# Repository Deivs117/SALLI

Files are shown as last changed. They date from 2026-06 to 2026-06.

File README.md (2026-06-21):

# SALLI: Salamander Autonomous Locomotion on Land Infrastructure

SALLI is an open-source, low-cost, and modular mechatronic platform designed to study bio-inspired terrestrial locomotion. Drawing inspiration from the sprawling gait of the salamander, this project integrates custom 3D-printed mechanical linkages, dedicated modular printed circuit boards (PCBs), lightweight embedded ESP-IDF firmware, and high-level Python control algorithms.

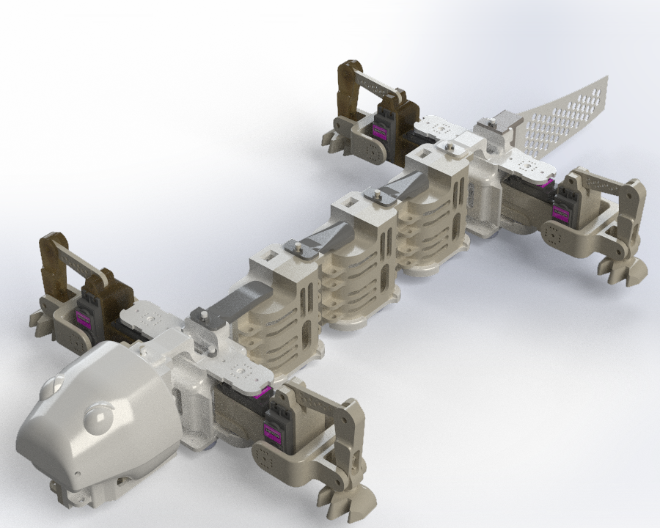
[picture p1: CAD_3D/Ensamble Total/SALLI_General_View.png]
SALLI General View


---

## Project Vision & Philosophy

Traditional robotics platforms often suffer from high manufacturing costs, complex monolithic assemblies, and poor reparability. SALLI was conceived under a different paradigm:
* **True Modularity:** Every physical segment—whether a spinal oscillator, a locomotor leg, or a sensory head—uses a standardized mechanical and electrical connection interface. Segments can be chain-linked dynamically to increase or decrease the robot's degrees of freedom (DoF).
* **Low Cost & Accessibility:** Designed to be accessible to students, researchers, and hobbyists. The structural parts are optimized for standard FDM 3D printing, and the electronics rely on budget-friendly, high-performance ESP32-C3 microcontrollers and standard micro servos.
* **Easy Maintenance & Repair:** Field repairs can be executed swiftly. Damage to a single segment does not compromise the whole robot; the offending module can be disconnected and swapped out in minutes.

---

## System Architecture

The project is structurally divided into four cohesive domains:

```mermaid
graph TD
    A[Control Codes - Python PC] <-->|UDP over Wi-Fi| B[Firmware - ESP-IDF Master AP]
    B <-->|UDP Multicast / Serial Bus| C[Firmware - ESP-IDF Slave Node]
    B -->|PWM Signals| D[Custom PCBs / Power Rails]
    C -->|PWM Signals| D
    D -->|Actuation| E[CAD 3D - Physical Modules]

```

1. **`CAD_3D/` (Mechanical Architecture):** Multi-segment structure utilizing bio-mimetic joint limits and sprawling kinematics.
2. **`PCBs/` (Electrical Architecture):** Modular bus system delivering isolated power lines (to prevent servo-induced voltage brownouts) and standardized signal traces.
3. **`Firmware/` (Embedded Systems):** High-efficiency ESP-IDF C-code implementing an Access Point control loop and UDP-based communication over ESP32-C3 chips.
4. **`ControlCodes/` (High-Level Control & Autonomy):** Python orchestrator supporting manual teleoperation, automatic parameter identification, and servo calibration.

---

## Repository Directory Tree

```text
SALLI/
├── .gitignore                   # Global file and directory exclusions
├── README.md                    # Root-level project documentation (This file)
│
├── CAD_3D/                      # Mechanical assemblies and components
│   ├── Cabeza V3/               # Sensory head module
│   ├── Cola/                    # Stabilizing tail segment
│   ├── Ensamble Total/          # Master digital design assembly
│   ├── Módulo de Patas V3/      # Sprawling leg kinematics module
│   ├── Oscilatorio V4/          # Daisy-chainable spinal segments
│   └── Patines/                 # Passive ground contact slide-pads
│
├── ControlCodes/                # High-level Python control ecosystem
│   ├── Calibration.py           # Multi-servo offset calibration utility
│   ├── SALLI.py                 # Core autonomy and CPG state engine
│   └── Teleoperation.py         # Human-in-the-loop manual controller
│
├── Firmware/                    # Low-level ESP-IDF software
│   ├── Acces Point Sally/       # Master AP, computational control, and state processor
│   └── WIFI_Movement/           # Slave node receiver executing raw joint positions
│
└── PCBs/                        # Electrical schematic and board layouts
    ├── Camera/                  # Visual feedback capture module
    ├── HeadModule/              # Central micro-controller carrier PCB
    ├── Legs_Module/             # High-current servo driver PCB
    └── Oscilatory/              # Passive signal-passthrough spine PCB

```

---

## Biological Locomotion Model

SALLI's movement is mathematically governed by a **Central Pattern Generator (CPG)** model. This system represents networks of coupled neural oscillators that generate rhythmic patterns without sensory feedback.

The phase relation between the body segments ($i$) and limbs ($j$) is modeled using coupled differential equations:

$$\frac{d\theta_i}{dt} = 2\pi \nu_i + \sum_{j} w_{ij} \sin(\theta_j - \theta_i - \phi_{ij})$$

Where:

* $\theta_i$ represents the instantaneous phase of the $i$-th oscillator.
* $\nu_i$ is the intrinsic frequency of the segment.
* $w_{ij}$ dictates the coupling strength between neighboring segments.
* $\phi_{ij}$ is the target phase bias defining traveling waves for swimming or crawling.

This math is processed in real-time between the `ControlCodes` layer and the `Firmware` layer to ensure fluid, life-like movements.

---

## Quick Start

### 1. Requirements & Tools

* **CAD:** Autodesk Fusion 360, SolidWorks, or FreeCAD to view STEP/STL files.
* **Firmware development:** Espressif ESP-IDF SDK (v5.1 or later recommended).
* **Control Station:** Python 3.10+ with standard networking libraries.

### 2. Basic Setup

To clone the repository and initialize the project:

```bash
git clone [https://github.com/YourUsername/SALLI.git](https://github.com/YourUsername/SALLI.git)
cd SALLI

```

---

## Academic Context

This project was developed at **Universidad Autónoma de Occidente (UAO)**, Cali, Colombia, within the Faculty of Engineering. It serves as an open-source platform to advance research in bio-inspired robotics, kinetic efficiency, and distributed embedded networks.

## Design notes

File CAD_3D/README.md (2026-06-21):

# SALLI: Mechanical CAD & Bio-Inspired Designs

This directory contains the entire three-dimensional mechanical framework of SALLI. The structural engineering is tailored for high accessibility, durability, and rapid assembly, allowing students and researchers to fabricate a bio-inspired robot using standard **Fused Deposition Modeling (FDM) 3D printers**.

---

## Directory Mapping & Module Functions

To accommodate global developers, the folder names are kept in Spanish as generated by our design pipeline, but correspond to the following technical subsystems:

| Folder Name | English Designation | Core Mechanical Role |
| :--- | :--- | :--- |
| `Cabeza V3` | **Head Module V3** | Houses the primary ESP32-C3 processor, sensory electronics, power switch routing, and visual streaming camera. |
| `Oscilatorio V4` | **Oscillatory Spine V4** | Standardized vertebrae module that provides one horizontal rotary Degree of Freedom (DoF) to form the lateral undulations of the spine. |
| `Módulo de Patas V3` | **Sprawling Leg Module V3** | Houses the micro servos responsible for controlling the crawling limbs, transforming standard rotary motion into forward driving force. |
| `Cola` | **Tail Module** | A series of passive/active segments that balance center of mass shifts and provide inertial stabilization. |
| `Patines` | **Underbody Slides / Skates** | Passive support structures positioned along the belly to minimize frictional dragging forces and maintain consistent ground clearance. |
| `Ensamble Total` | **Master CAD Assembly** | Complete workspace containing tolerances, fast assembly fasteners, and inter-segment limits. |

---

## Mechanical Modularity Philosophy

The backbone of SALLI relies on a **dovetail-inspired sliding locking mechanism** secured with standard metric machine screws. 

```mermaid
flowchart LR
    %% Definición de los Módulos Físicos
    ModuleA["Module N-1: Passive Tail"]
    ModuleB["Module N: Active Actuator"]

    %% Interfaz Central de Conexión
    subgraph Interface ["Connector Interface"]
        direction TB
        Slot["Dovetail Slot Joint"]
        Bolt["M3 Retaining Bolt"]
        Slot --- Bolt
    end

    %% Relaciones de Ensamble y Dirección de Acople
    ModuleA ==>|Sliding Alignment| Slot
    ModuleB ==>|Mechanical Lock| Bolt

    %% Estilos de Ingeniería Libres de Emojis
    style ModuleA fill:#1a1a1a,stroke:#444,stroke-width:2px,color:#fff
    style ModuleB fill:#1a1a1a,stroke:#444,stroke-width:2px,color:#fff
    style Interface fill:#2d2d2d,stroke:#666,stroke-width:1px,color:#fff
    style Slot fill:#3d3d3d,stroke:#777,color:#fff
    style Bolt fill:#3d3d3d,stroke:#777,color:#fff
```

* **No Glue Required:** All connections are held in place mechanically, ensuring that cracked components can be easily unscrewed, reprinted, and replaced.
* **Symmetrical Design:** The spinal modules share symmetrical left/right geometry, minimizing the unique parts inventory required for manufacturing.
* **Adaptive Kinematics:** By modifying the number of `Oscilatorio` modules, you can alter the physical body length, shifting the gait dynamics from a compact lizard style to an elongated serpentine flow.

---

## Manufacturing & FDM Print Specifications

To achieve optimal strength-to-weight ratios without requiring industrial printers, we recommend printing the parts using the following settings:

* **Material:** **PETG** (Highly recommended for high impact strength and natural flex tolerance under heavy joint torques) or **PLA+** (for easy printing with high tensile strength).
* **Layer Height:** `0.2 mm` (Balanced speed and feature tolerance).
* **Infill Density:** * Spine/Structural parts: `30%` Gyroid or Grid infill.
* Leg linkages/Connectors: `50%` Gyroid infill (Crucial for withstanding torsional shear stress).

* **Wall Lines:** Minimum `3` perimeter loops.
* **Orientation:** Print all modules with their flat connector faces touching the build plate to eliminate the need for excessive support structures.

---

## Hardware Fasteners Bill of Materials (BOM)

To assemble the CAD files, ensure you have the following hardware:

* **Screws:** M3 socket head screws (various lengths: $8\text{ mm}$, $12\text{ mm}$, and $16\text{ mm}$).
* **Nuts:** M3 hex locknuts (nyloc recommended to prevent loosening from walking vibrations).
* **Servos:** High-torque metal-geared micro servos (e.g., MG90S or compatible standard micro-sizes).

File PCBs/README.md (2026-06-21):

# SALLI: Custom Electronic PCBs

This directory contains the electrical designs for SALLI's custom printed circuit boards. The electronic system is engineered to solve a common pitfall in amateur robotics: messy, unreliable wiring harnesses that introduce high resistance, noise, and power failures.

---

## Electrical Architecture Overview

SALLI uses a decentralized, modular electrical bus system. Power is distributed along the spine via a ruggedized internal backbone, preventing major voltage drops from affecting the master microcontroller.

```mermaid
flowchart TD
    %% Definición de Bloques Principales
    Battery["Main Battery Pack<br>(2S LiPo / 7.4V)"]
    RegServo["Servo Regulators<br>(5V - 6V)"]
    RegLogic["Logic Regulators<br>(3.3V)"]
    
    %% Representación del Bus Centralizado
    subgraph Bus ["SALLI Power & Communication Bus"]
        direction LR
        Lines["Power Rails & Signal Traces"]
    end

    %% Módulos de Destino (PCBs)
    Head["HeadModule<br>(Master Processing)"]
    Osc["Oscilatory<br>(Spine Segment)"]
    Legs["Legs_Module<br>(High-Current Driver)"]

    %% Conexiones e Interconexión Eléctrica
    Battery ==>|Raw VCC| RegServo
    Battery -->|Raw VCC| RegLogic
    
    RegServo ==>|High-Current Servo VCC| Lines
    RegLogic -->|Isolated Clean 3.3V| Lines

    Lines ==> Head
    Lines ==> Osc
    Lines ==> Legs

    %% Estilos de Ingeniería Avanzada (Sin Emojis)
    style Battery fill:#1a1a1a,stroke:#bf616a,stroke-width:2px,color:#fff
    style RegServo fill:#2d2d2d,stroke:#d08770,stroke-width:1px,color:#fff
    style RegLogic fill:#2d2d2d,stroke:#ebcb8b,stroke-width:1px,color:#fff
    style Bus fill:#232831,stroke:#81a1c1,stroke-width:2px,color:#fff
    style Lines fill:#3b4252,stroke:#88c0d0,stroke-width:1px,color:#fff
    style Head fill:#1a1a1a,stroke:#4c566a,stroke-width:1px,color:#fff
    style Osc fill:#1a1a1a,stroke:#4c566a,stroke-width:1px,color:#fff
    style Legs fill:#1a1a1a,stroke:#4c566a,stroke-width:1px,color:#fff
    
    %% Definición de grosores de línea para diferenciar potencia de lógica
    linkStyle 0 stroke:#bf616a,stroke-width:3px;
    linkStyle 1 stroke:#ebcb8b,stroke-width:1px;
    linkStyle 2 stroke:#d08770,stroke-width:3px;
    linkStyle 3 stroke:#ebcb8b,stroke-width:1px;
```

---

## Board Subsystems & Responsibilities

The electrical system is divided into four main board profiles:

### 1. `HeadModule` (Master Processing PCB)

The central board of the robot, acting as SALLI's head controller.

* **MCU Support:** Integrates the footprint for the **ESP32-C3 Mini** board.
* **Power Filtering:** Features heavy ceramic and electrolytic capacitor banks to filter out high-frequency noise induced by servo inductive kickbacks.
* **Sensor Hub:** Routes dedicated pins for IMUs (Inertial Measurement Units for tilt and balance detection) and external range sensors.

### 2. `Oscilatory` (Spine Segment PCB)

These are passive/semi-active distribution boards designed to be chain-linked together.

* **The SALLI Bus:** Passes power (VCC and GND) and communication channels downstream to consecutive modules.
* **Servo Tap:** Provides local, filtered power connectors for the local spinal deflection servo, keeping cabling lengths under $20\text{ mm}$.

### 3. `Legs_Module` (High-Current Driver Board)

Because the limbs support the entire weight of the robot and drive forward crawling forces, they demand significant active currents.

* **High-Current Traces:** Features wide copper traces capable of handling sustained currents of up to $3\text{ A}$ during crawling cycles.
* **Independent Power Regulation:** Standardizes opto-couplers or isolation resistors to prevent sudden physical motor stalls from corrupting the main microcontroller's logical operations.

### 4. `Camera` (Vision Expansion Board)

An optional expansion PCB tailored to hold camera modules (such as ESP32-CAM or specialized small SPI cameras) to enable visual-spatial telemetry.

---

## Design Guidelines

* **Trace Width Selection:** * Power paths ($VCC\_SERVO$, $GND$) are set to a minimum of `1.5 mm` width to minimize resistance and prevent thermal stress under heavy load.
* Logic lines ($TX$, $RX$, $PWM$) are kept at standard `0.254 mm` traces.

* **Decoupling Strategy:** Each module places a `100uF` electrolytic capacitor directly in parallel with the local servo power terminal, supplemented by a standard `0.1uF` ceramic capacitor close to the logic rails to handle high-frequency voltage ripples.
* **Standardized Pin Headers:** Connectors use standard, highly accessible, polarized headers (like JST-XH or XT30/XT60 for power entry) to ensure mistake-proof assembly by students.

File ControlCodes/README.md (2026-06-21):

# SALLI: Python High-Level Control Codes

This directory contains the high-level Python software suite designed to orchestrate SALLI's telemetry, user interaction, automated object-tracking loops, and physical joint calibration. These components interface directly with the ESP32-C3 master microcontroller over local network protocols to close the control loop.

---

## Software Component Architecture

The Python workstation layer processes non-real-time heavy computations (such as deep learning inference and graphic user interfaces) and communicates with SALLI's local Wi-Fi gateway.

```mermaid
graph TD
    subgraph Workstation [High-Level Workstation]
        A[Teleoperation.py] -->|Subprocess Launch| B[Calibration.py]
        C[SALLI.py] -->|YOLOv8 Engine| D[Inference Thread]
        D -->|Target Vector Calculation| E[Network Request Loop]
    end

    subgraph ESP32 [Embedded Gateway]
        F[Master ESP32-C3 AP]
        G[ESP32-CAM Board]
    end

    E -->|HTTP REST /drive| F
    B -->|HTTP POST /calib| F
    A -->|HTTP GET /frame| G

```

### 1. SALLI.py: Vision-Based Autonomous Navigator

This application establishes an autonomous closed-loop tracking system using a local webcam or HTTP camera stream. It utilizes a custom-trained **YOLO (You Only Look Once)** object detection network to identify targets and dynamically adjust the robot's locomotion vector.

* **Asynchronous Deep Learning Inference:** A dedicated background thread runs the YOLO engine (`my_model.pt`) on incoming image buffers, maintaining frame-rate stability on the main UI thread.
* **Proportional Target Tracking:** Translates spatial coordinate deviations of target bounding boxes into steering adjustments and speed curves.
* **Proximity Stop Safeguards:** Automatically switches states to idle/stop when the target bounding box area exceeds a safety threshold, preventing physical collisions.

### 2. Teleoperation.py: Interactive Driver Station

Provides a graphical user interface (GUI) developed in Tkinter with a dark palette.

* **Asynchronous Video Stream Receiver:** Connects to an external ESP32-CAM module, pulling JPEG frames continuously via HTTP GET requests and dynamically resizing the viewport buffer to maintain low latencies.
* **Remote Mode Transitioning:** Sends immediate state changes to the master robot, switching operating modes (`calib`, `preview`, `run`) via high-speed HTTP parameters.
* **Dynamic Controller Spawning:** Spawns the calibration tool as an independent sub-process, ensuring modular execution.

### 3. Calibration.py: Joint Offset Tuner

Compensates for mechanical assembly tolerances and variations across budget analog micro-servos.

* **Trimming Array Constructor:** Allows users to adjust mechanical offsets for 14 independent servo lines divided into logical anatomical groups:
* Left and Right Limbs (`p1` through `p8`)
* Anterior and Posterior Vertebrae (`o1` through `o6`)

* **NVS Serializer:** Collects active slider adjustments and structures a serialized JSON payload transmitted via HTTP POST. This configuration is written directly to the non-volatile storage (NVS) partition of the ESP32-C3 chip.

---

## Mathematical Formulations

To ensure a high level of technical rigor, the mechanical, kinematic, and vision processing layers are governed by the following mathematical frameworks.

### 1. Servo Offset Projection Model

Let $\theta_{\text{logical}, i}$ be the abstract, mathematically calculated joint angle outputted by the locomotion algorithm for servo $i$, where $\theta_{\text{logical}, i} \in [-90^\circ, 90^\circ]$.

Due to physical mounting misalignments, a pure logical angle does not map to a physically straight joint. We define $\theta_{\text{base}} = 90^\circ$ as the physical midpoint of the servo's standard $180^\circ$ range. The final commanded angle transmitted to the physical actuator $\theta_{\text{target}, i}$ is calculated as:

$$\theta_{\text{target}, i} = \theta_{\text{logical}, i} + \theta_{\text{base}} + \Delta\theta_i$$

Where:

* $\Delta\theta_i \in [-45^\circ, 45^\circ]$ represents the calibration trim offset for servo $i$, modified in `Calibration.py`.

During calibration mode, the software enforces $\theta_{\text{logical}, i} = 0^\circ$. Thus, the physical output reduces to:

$$\theta_{\text{target}, i} = 90^\circ + \Delta\theta_i$$

By adjusting $\Delta\theta_i$ until the joint is perfectly perpendicular, the system captures mechanical error offsets and saves them to the ESP32-C3 NVS.

### 2. YOLO-Based Closed-Loop Proportional Steering Logic

When running in autonomous tracking mode (`SALLI.py`), the tracking error $e(t)$ is computed from the bounding box's horizontal centroid $x_{\text{bbox}}$ relative to the total horizontal frame resolution $W$:

$$e(t) = \frac{x_{\text{bbox}} - \frac{W}{2}}{\frac{W}{2}} = \frac{2 \cdot x_{\text{bbox}}}{W} - 1$$

Where:

* $e(t) \in [-1.0, 1.0]$. A negative value indicates the target is to the left, and a positive value indicates the target is to the right.

To prevent joint wear from continuous micro-oscillations, we implement a symmetrical deadzone $\delta_{\text{dead}}$:

$$\beta(t) = \begin{cases} 
K_p \cdot e(t) & \text{if } |e(t)| > \delta_{\text{dead}} \\
0 & \text{if } |e(t)| \le \delta_{\text{dead}} 
\end{cases}$$

Where:

* $\beta(t)$ represents the steering bias parameter.
* $K_p$ is the proportional tracking gain.

### 3. Kinematic Traveling Wave Synthesis with Steering Bias

The target spinal angles along the vertebrae are synthesized using a discretized traveling sine wave. For the $i$-th spine segment at time $t$:

$$\theta_{\text{logical}, i}(t) = A_i \sin(\omega t - i \cdot k) + \beta(t)$$

Where:

* $A_i$ is the maximum allowed mechanical amplitude of the segment.
* $\omega$ is the joint angular velocity, controlling the speed of the wave.
* $k$ is the spatial phase lag (wave-number) defining the wave's wavelength.
* $\beta(t)$ is the steering bias derived from the vision feedback controller.

---

## Time Synchronization and Data Exchange

This sequence diagram illustrates the non-blocking coordination and HTTP REST handshakes between the human operator, the Python control station, and SALLI's embedded nodes during live operations.

```mermaid
sequenceDiagram
    autonumber
    actor Operator as Operator / User
    participant PyStation as Python Control Station
    participant MasterAP as ESP32-C3 Master (Access Point)
    participant CamNode as ESP32-CAM Node

    Note over PyStation: Thread 1: Main GUI Event Loop (100 ms)
    Note over PyStation: Thread 2: Video Receiver Stream (~30 fps)

    loop MJPEG Video Pipeline
        PyStation->>CamNode: HTTP GET /frame
        CamNode-->>PyStation: Return JPEG Buffer
        PyStation->>PyStation: Process Frame & Update Canvas
    end

    rect rgb(20, 30, 45)
        Note over PyStation: User Calibration Phase
        Operator->>PyStation: Adjust Trimming Slider (Servo i)
        PyStation->>MasterAP: HTTP POST /calib (JSON: {"offset_i": val})
        Note over MasterAP: Store config to NVS flash
        MasterAP-->>PyStation: HTTP 200 OK Status
        PyStation->>MasterAP: HTTP GET /mode?state=preview
        Note over MasterAP: Project: 90° + Offset
        MasterAP-->>PyStation: HTTP 200 OK Status
    end

    rect rgb(30, 20, 25)
        Note over PyStation: Live Teleoperation Phase
        Operator->>PyStation: Move Joystick / Press Directional Key
        PyStation->>PyStation: Compute Gait Scaling Vectors
        PyStation->>MasterAP: HTTP GET /drive?dir=F&pct=85&resp=70
        Note over MasterAP: Parse Locomotion Coefficients
        Note over MasterAP: Compute target duty cycles for LEDC Registers
        MasterAP-->>PyStation: HTTP 200 OK Status
    end

```

---

## Installation & Launch

### Prerequisite Dependencies

To run the high-level Python suite, install the required packages using pip:

```bash
pip install numpy opencv-python pillow ultralytics pygame

```

### Running the Components

#### 1. Running Servo Calibration

Launch the standalone calibration graphical interface to offset mechanical errors:

```bash
python Calibration.py

```

#### 2. Launching Teleoperation

Run the teleoperation driver panel to establish control over SALLI's local network gateway:

```bash
python Teleoperation.py

```

#### 3. Launching YOLO Autonomous Control

Verify that your webcam or external stream is operational, check the model path in the source code, and run:

```bash
python SALLI.py

```

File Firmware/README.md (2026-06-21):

# SALLI: ESP-IDF Firmware Ecosystem

This directory contains the dual-node embedded firmware framework developed for SALLI. The entire subsystem is built using Espressif's native **ESP-IDF (IoT Development Framework) v5.1+** for the **ESP32-C3 Mini** microcontroller. By bypassing the Arduino abstraction layer, this firmware achieves microsecond-precision hardware timing, efficient multi-tasking via **FreeRTOS**, and low-overhead network serialization.

---

## Distributed Firmware Architecture

SALLI's movement and data routing are handled by two software execution profiles deployed across distinct physical units:

1. **Master Node (`Acces Point Sally`):** Acts as the centralized coordinator located in the robot's Head Module. It initializes a Wi-Fi SoftAP, hosts an HTTP REST API server, loads/saves calibration arrays from Flash memory, computes gait kinematics using deterministic timers, and distributes targeting data.
2. **Slave Node (`WIFI_Movement`):** Deployed across localized motor-driver segments. It connects to the Master SoftAP as a Station (STA), opens an HTTP client polling loop, parses joint angles, and drives hardware timers using the ESP32 LEDC peripheral.

```mermaid
graph TD
    subgraph MasterNode [Head Module: Master Access Point]
        M_WiFi[ESP-IDF Wi-Fi SoftAP]
        M_HTTP[HTTP REST Server]
        M_NVS[NVS Flash Manager]
        M_Timer[High-Resolution esp_timer]
        M_Gait[Gait Engine: Central Pattern Generator]
        
        M_WiFi --> M_HTTP
        M_NVS <-->|Load/Save Offsets| M_HTTP
        M_Timer -->|Trigger 20ms Loop| M_Gait
        M_Gait -->|Update Angles Buffer| M_HTTP
    end

    subgraph ClientLayer [High-Level Orchestration]
        Py_Ctrl[Python Station / YOLO]
    end

    subgraph SlaveNode [Legs/Spine Modules: Station Nodes]
        S_WiFi[Wi-Fi Station Mode]
        S_Client[HTTP Client Poll Task]
        S_JSON[cJSON Parser Engine]
        S_LEDC[LEDC PWM Driver]
        
        S_WiFi --> S_Client
        S_Client --> S_JSON
        S_JSON --> S_LEDC
    end

    Py_Ctrl -->|HTTP GET /drive<br>HTTP POST /calib| M_HTTP
    S_Client -->|HTTP GET /angles?id=N| M_HTTP

```

---

## Master Node Execution & FreeRTOS Task Lifecycle

The Master firmware coordinates multiple asynchronous operations by distributing computational load across FreeRTOS task handles and hardware interrupts.

### State Machine Transitions

The system operation relies on three primary states managed by an internal enum (`run_mode_t`):

* `MODE_IDLE`: Servos are soft-locked; no traveling waves are computed.
* `MODE_CALIB`: The network forces a raw neutral output ($90^\circ$ baseline) across all channels, bypassing the calibration Lookup Tables (LUT) to isolate physical alignment errors.
* `MODE_RUN`: Active state. The high-resolution hardware timer synthesizes real-time sinewaves and updates them by injecting the saved NVS mechanical offsets.

```mermaid
stateDiagram-v2
    [*] --> INITIALIZATION : Boot / Core Power-On
    
    state INITIALIZATION {
        [*] --> NVS_Flash_Init
        NVS_Flash_Init --> Netif_And_Event_Loop
        Netif_And_Event_Loop --> WiFi_SoftAP_Start
        WiFi_SoftAP_Start --> HTTP_Server_Register
    }
    
    INITIALIZATION --> MODE_IDLE : Default State Entry
    
    state MODE_IDLE {
        [*] --> Idle_Active
        note right of Idle_Active
            Gait computation stopped.
            Servos holding last position.
        end note
    }
    
    MODE_IDLE --> MODE_CALIB : HTTP Request /mode?state=calib
    MODE_CALIB --> MODE_IDLE : HTTP Request /mode?state=idle
    
    state MODE_CALIB {
        [*] --> Calib_Active
        note right of Calib_Active
            Forces pure 90° across all joints.
            Bypasses NVS offset summation.
        end note
    }
    
    MODE_CALIB --> MODE_RUN : HTTP Request /mode?state=run
    MODE_RUN --> MODE_IDLE : HTTP Request /mode?state=idle
    
    state MODE_RUN {
        [*] --> Run_Active
        note right of Run_Active
            Core esp_timer active.
            Generates kinematics waves.
            Applies: Base + Offset + Wave
        end note
    }

```

### Deterministic Kinematic Synthesis Loop

Rather than using loose FreeRTOS task delays which suffer from scheduler jitter, the rhythmic locomotion patterns are calculated via a hardware-backed high-resolution timer interrupt (`esp_timer_handle_t`) configured to fire precisely every $\Delta t = 20\text{ ms}$ ($50\text{ Hz}$).

To enforce joint protection and limit acceleration, target values are fed through an analytical convergence function that acts as a low-pass slew rate limiter:

$$\theta_{\text{current}}(t) = \theta_{\text{current}}(t-\Delta t) + \text{clamp}\left(\theta_{\text{target}}(t) - \theta_{\text{current}}(t-\Delta t), -\Omega_{\text{max}}\cdot\Delta t, \Omega_{\text{max}}\cdot\Delta t\right)$$

Where:

* $\Omega_{\text{max}}$ represents the maximum allowable angular velocity expressed in degrees per second ($dps$).

---

## Network Protocol & API Endpoint Matrix

The Master Node exposes an embedded HTTP server listening on port `80`. Slave nodes and external base stations communicate with the robot using standardized REST endpoints.

| Endpoint | HTTP Method | Target Clients | Query Parameters / Payload JSON | Technical Behavior |
| --- | --- | --- | --- | --- |
| `/mode` | `GET` | Python GUI / Workstation | `?state=[run|calib|idle|preview]` | Transitions the global enum state machine and alters algorithmic data routing. |
| `/drive` | `GET` | Python Autonomous Loop | `?dir=[F|B|L|R]&pct=[0-100]&resp=[0-100]` | Modifies wave attributes: updates travel directions, scales overall amplitudes, and shifts steering variables ($\beta$). |
| `/calib` | `POST` | `Calibration.py` Utility | JSON payload containing an array of 14 signed integer offset parameters. | Writes calibration parameters directly into the NVS Flash partition `sally/offsets`. |
| `/angles` | `GET` | Slave `WIFI_Movement` Nodes | `?id=[0-7]` | Serializes the requested segment array from the central memory block into a JSON string format. |

### Network Payload JSON Specification (Example)

When a slave node assigned to a leg module requests data from the master via `/angles?id=4`, the Master server constructs the following structured JSON response packet:

```json
{
  "device_id": 4,
  "period": 2,
  "angles": [84.50, 92.15, 88.00, 90.00]
}

```

---

## Local Hardware Actuation (LEDC Peripheral Driver)

When a node receives its targets via network serialization, it decodes the payload using the `cJSON` component and updates its hardware profiles. The actual positioning of the analog micro-servos is controlled by translating logical degrees into raw timer ticks using the ESP32-C3 **LEDC** peripheral interface.

```mermaid
graph LR
    A[cJSON Floats: Degrees Array] -->|Validation: 0° to 180°| B[Hardware Mapping Equation]
    B -->|Calculated Pulse Width Time| C[Duty Cycle Register Translation]
    C -->|Write Bits to LEDC HW Channel| D[Physical Servo Actuator]

```

### Mathematical PWM Register Mapping

The hardware timing configurations are defined as follows:

* **PWM Frequency ($f_{\text{pwm}}$):** $50\text{ Hz}$ (Standard analog servo repetition control rate, equivalent to a $20\text{ ms}$ baseline window period).
* **Timer Counter Resolution ($R$):** $14\text{ bits}$ ($\text{Max Ticks} = 2^{14} - 1 = 16,383$).

The absolute pulse-width times ($T_{\text{pulse}}$) required to drive standard micro-servos are bounded between a $0.5\text{ ms}$ minimum limit and a $2.5\text{ ms}$ maximum limit:

$$T_{\text{pulse}}(\theta) = 0.5\text{ ms} + \left(\frac{\theta}{180^\circ}\right) \cdot (2.0\text{ ms})$$

To find the corresponding integer count value ($D_{\text{reg}}$) for the 14-bit duty cycle register, the embedded firmware computes the following transformation:

$$D_{\text{reg}}(\theta) = \left( \frac{T_{\text{pulse}}(\theta)}{20\text{ ms}} \right) \cdot (2^{14} - 1) = \left( \frac{0.5\text{ ms} + \frac{\theta}{180^\circ} \cdot 2.0\text{ ms}}{20\text{ ms}} \right) \cdot 16,383$$

Evaluating the linear boundary coefficients simplifies the hardware translation script to:

$$D_{\text{reg}}(\theta) = \text{round}\left( 409.575 + \theta \cdot 9.1016 \right)$$

This direct equation maps any raw input angle $\theta \in [0^\circ, 180^\circ]$ to its corresponding bit array value, enabling immediate register updates via the native API call `ledc_set_duty()`.

---

## Low-Level Memory Management: Non-Volatile Storage (NVS)

SALLI preserves its physical joint calibrations across complete power cuts by reading and writing variables into the flash chip's NVS partition.

```mermaid
flowchart TD
    subgraph Flash ["ESP32-C3 Flash Memory"]
        subgraph Partition ["'sally' Namespace Partition"]
            direction LR
            subgraph Table ["Data Structure Mapping"]
                direction TB
                K1["Key Name: 'offsets'"] 
                T1["Data Type: int8_t Array [14 elements]"]
                K1 --- T1
            end
        end
    end

    %% Estilos de los contenedores y nodos
    style Flash fill:#1a1a1a,stroke:#333,stroke-width:2px,color:#fff
    style Partition fill:#2d2d2d,stroke:#555,stroke-width:1px,color:#fff
    style Table fill:#222,stroke:#444,stroke-width:1px,color:#fff
    style K1 fill:#3d3d3d,stroke:#777,color:#fff
    style T1 fill:#3d3d3d,stroke:#777,color:#fff
```

### Flash Read / Write Operational Sequence

1. **Boot Initialization:** During `app_main`, the function `nvs_flash_init()` mounts the physical block storage. If a size mismatch error is returned, the sectors are formatted and re-initialized.
2. **Handle Allocation:** The application requests a secure communication link by calling `nvs_open("sally", NVS_READWRITE, &my_handle)`.
3. **Array Extraction:** On initialization, `nvs_get_blob(my_handle, "offsets", target_array, &length)` retrieves the signed 8-bit integer calibration array. If the key is missing, a default zero-vector is generated.
4. **Serialization and Commits:** When a configuration payload hits the `/calib` REST target, the input data array updates the active volatile registers. It is then serialized into the storage page via `nvs_set_blob()`, followed immediately by an explicit `nvs_commit()` call to flush the registers to physical memory blocks.

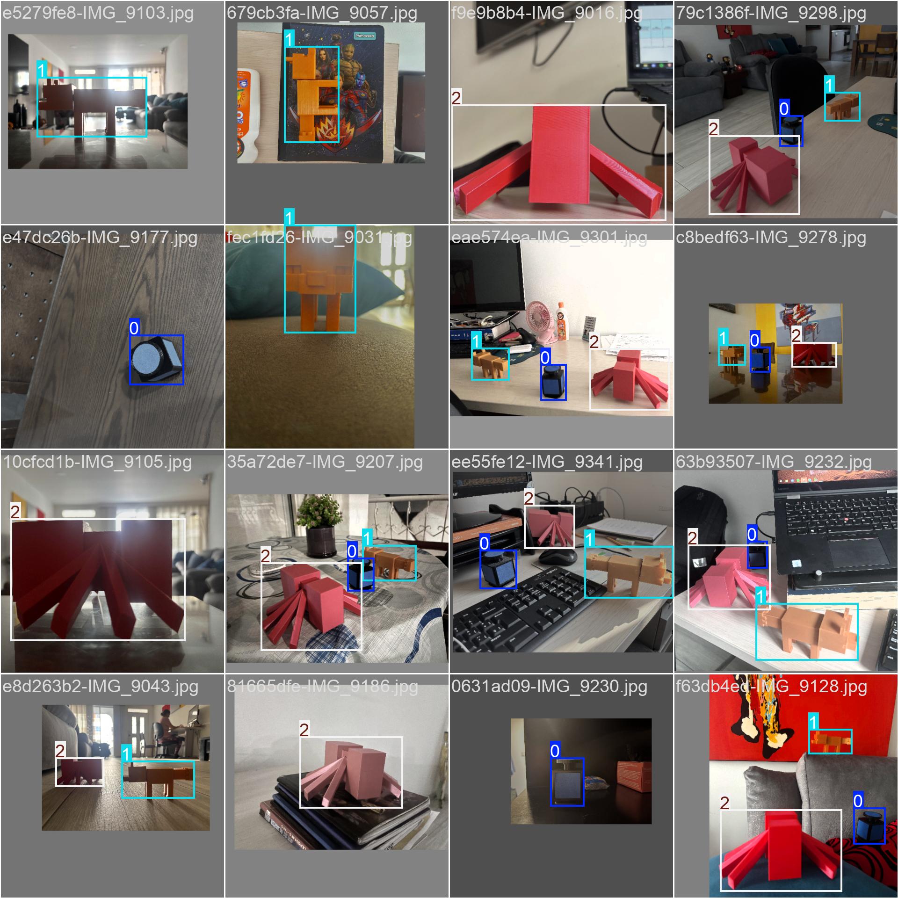
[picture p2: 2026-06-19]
YOLO/my_model/train/train_batch901.jpg

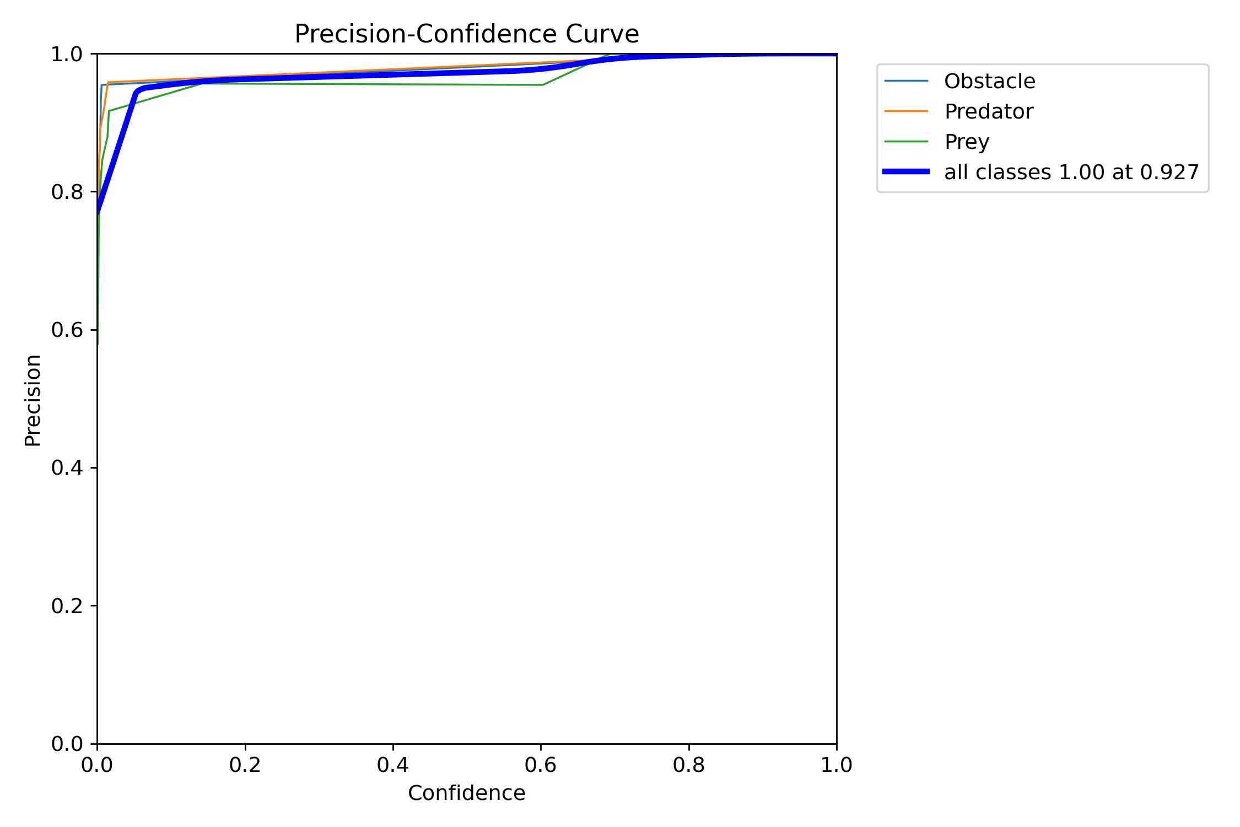
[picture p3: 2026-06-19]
YOLO/my_model/train/BoxP_curve.png

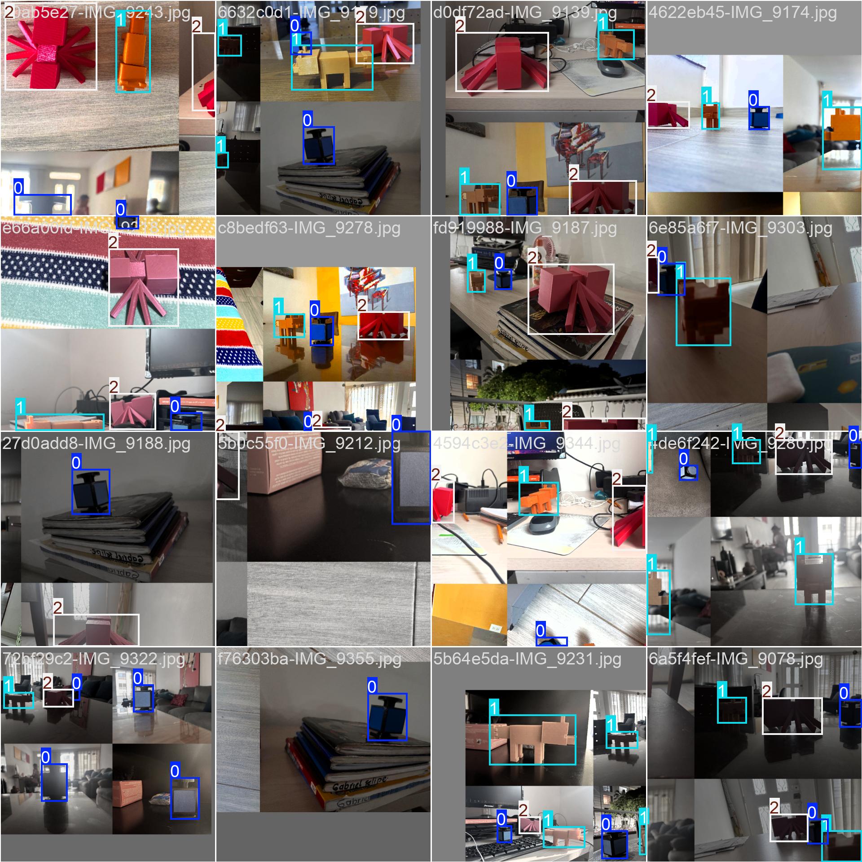
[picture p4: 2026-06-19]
YOLO/my_model/train/train_batch2.jpg

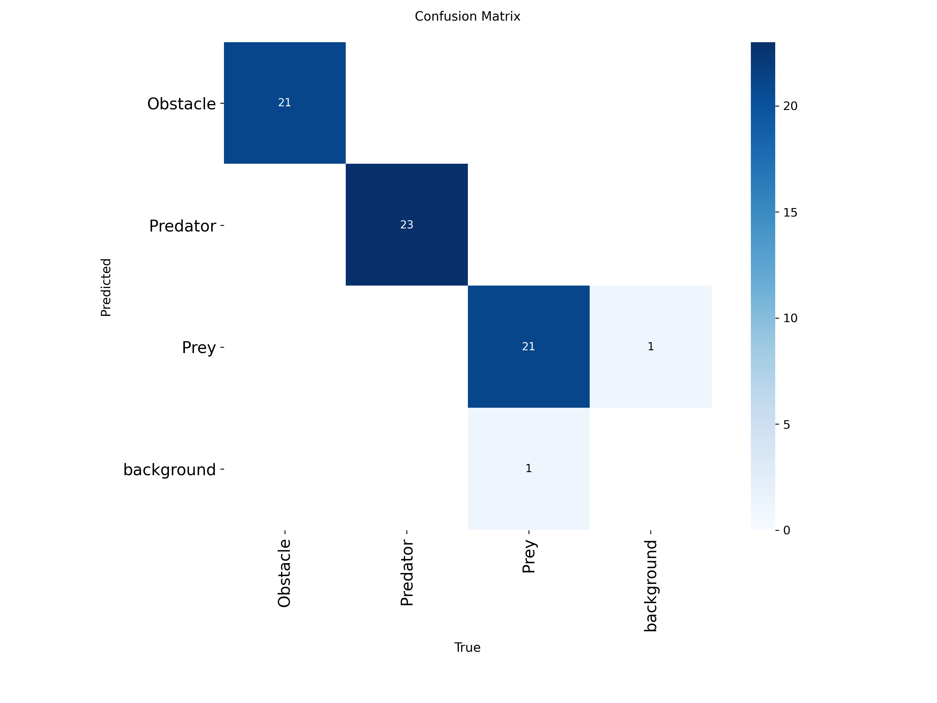
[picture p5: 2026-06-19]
YOLO/my_model/train/confusion_matrix.png

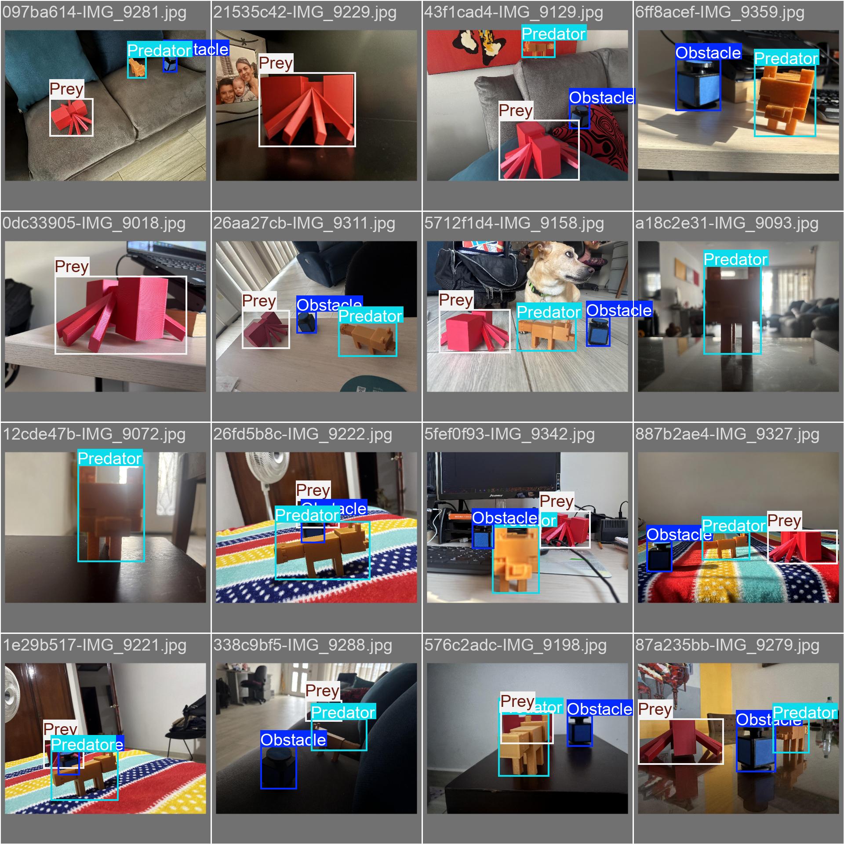
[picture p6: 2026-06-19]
YOLO/my_model/train/val_batch0_labels.jpg

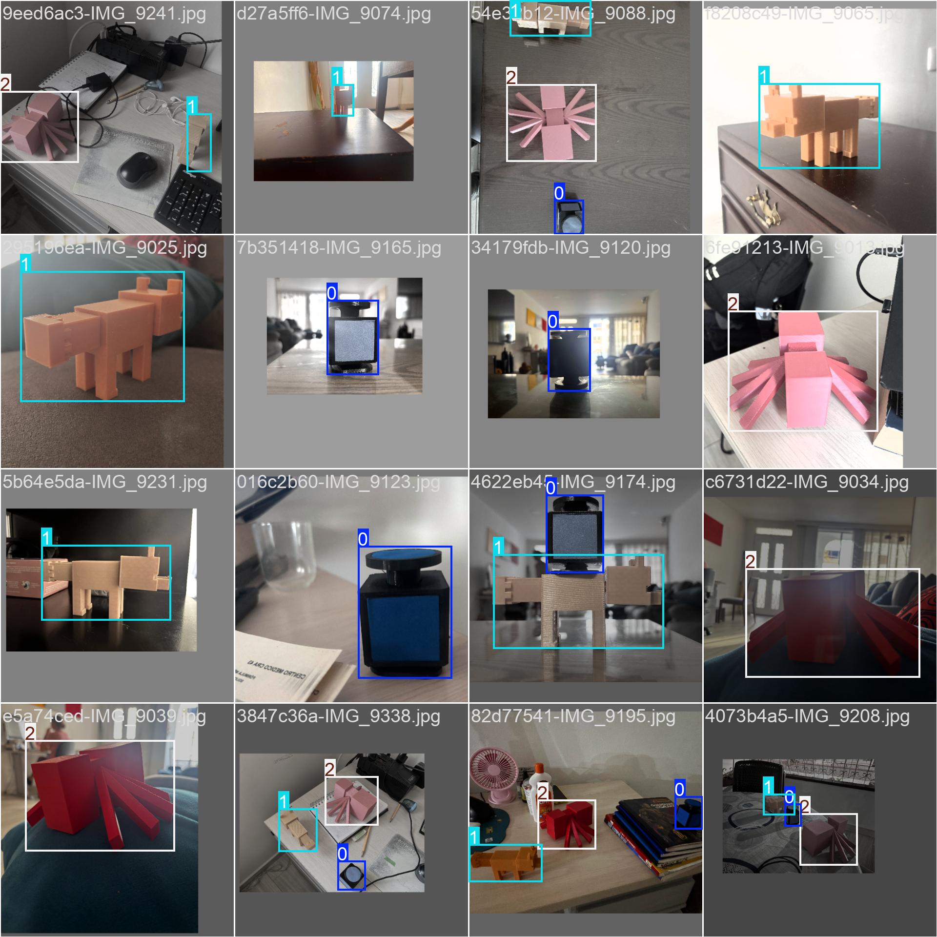
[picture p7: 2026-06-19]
YOLO/my_model/train/train_batch900.jpg

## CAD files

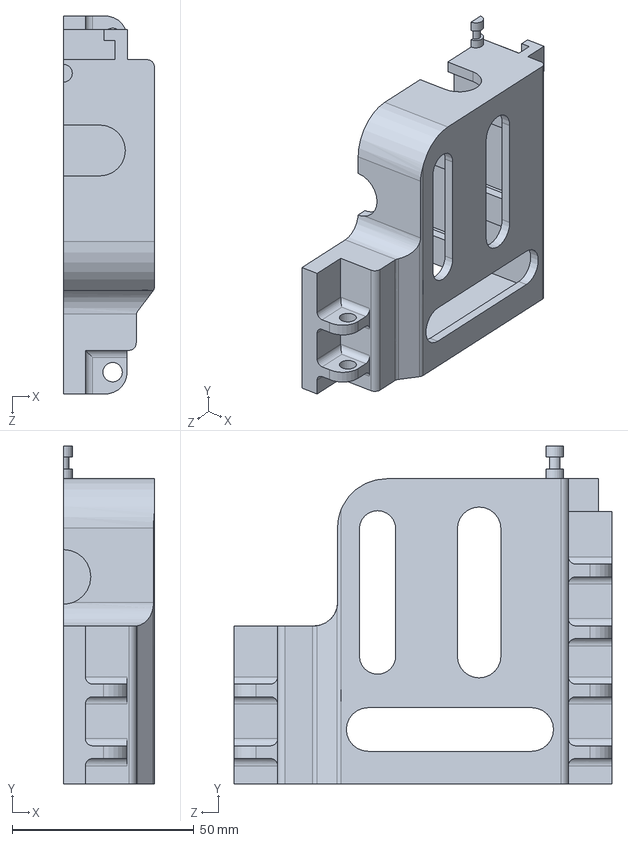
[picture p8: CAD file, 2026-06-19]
CAD_3D/Cabeza V3/Head_V3.SLDPRT
25.0 x 93.0 x 104.0 mm

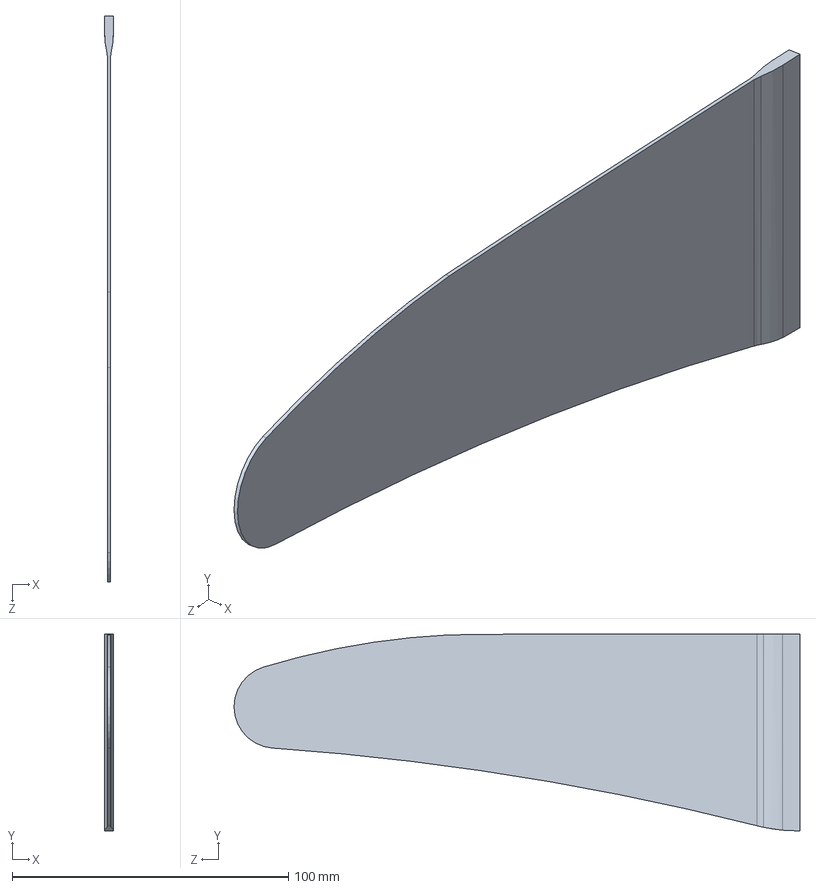
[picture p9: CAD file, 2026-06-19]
CAD_3D/Cola/ALETA.SLDPRT
3.16 x 71.3 x 205.0 mm

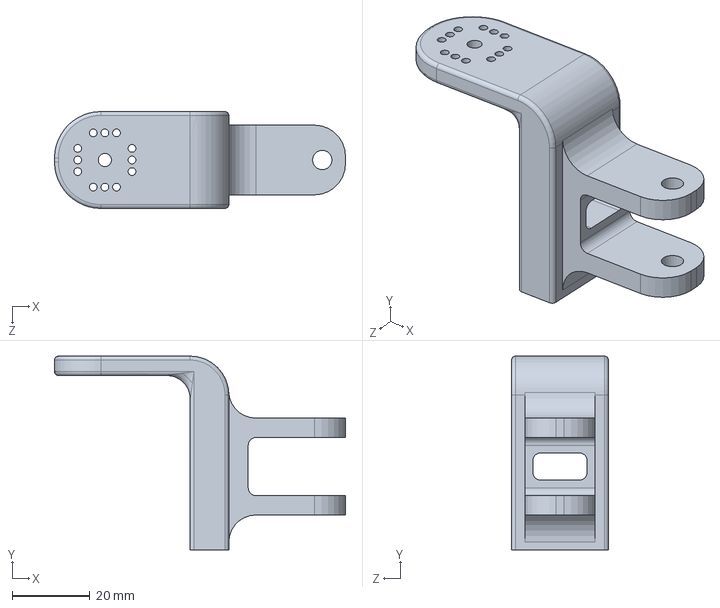
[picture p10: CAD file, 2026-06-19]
CAD_3D/Módulo de Patas V3/link1.SLDPRT
75.1 x 50.0 x 25.0 mm

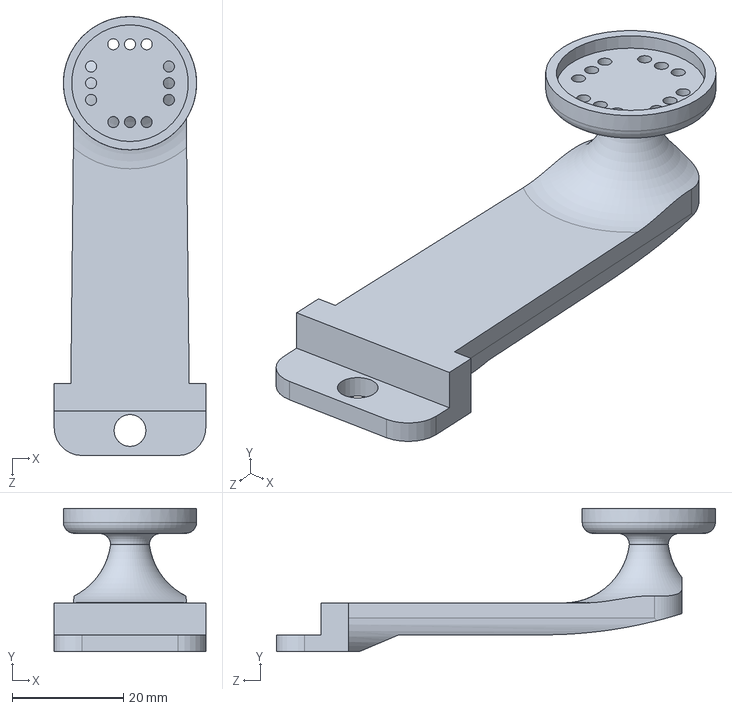
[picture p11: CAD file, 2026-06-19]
CAD_3D/Oscilatorio V4/Pieza conectora Patas.SLDPRT
27.3 x 25.8 x 79.0 mm

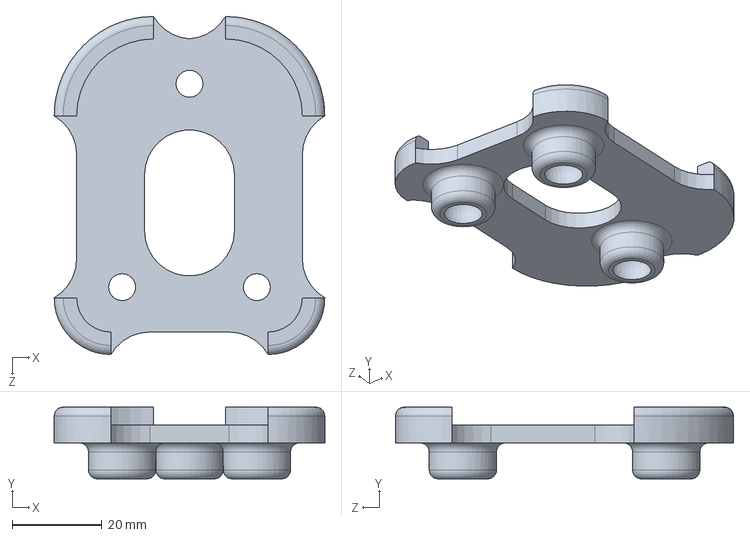
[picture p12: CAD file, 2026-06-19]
CAD_3D/Patines/PatínOsc_V2.SLDPRT
60.2 x 16.0 x 75.2 mm

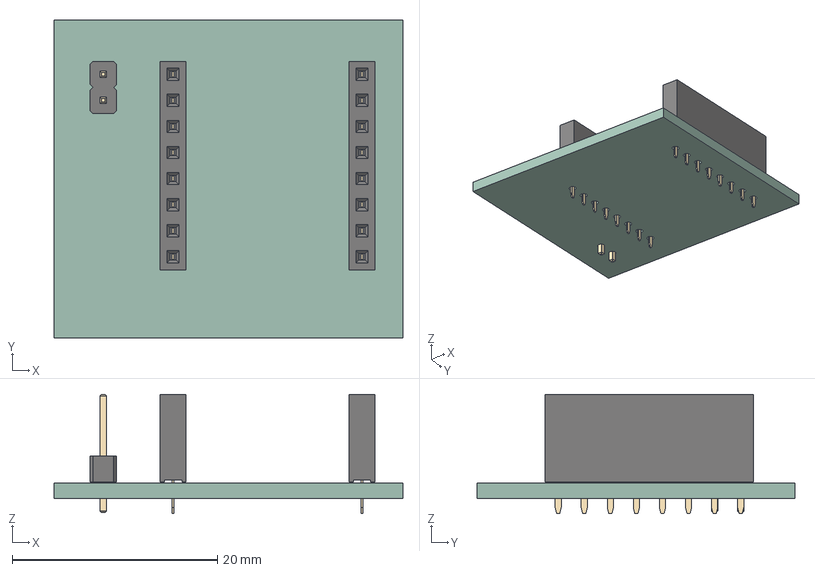
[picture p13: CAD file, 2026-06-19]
PCBs/Camera/Cámara.step
34.0 x 31.0 x 11.6 mm
PinSocket_1x08_P2.54mm_Vertical x 2
PinHeader_1x02_P2.54mm_Vertical
CÃ¡mara_PCB

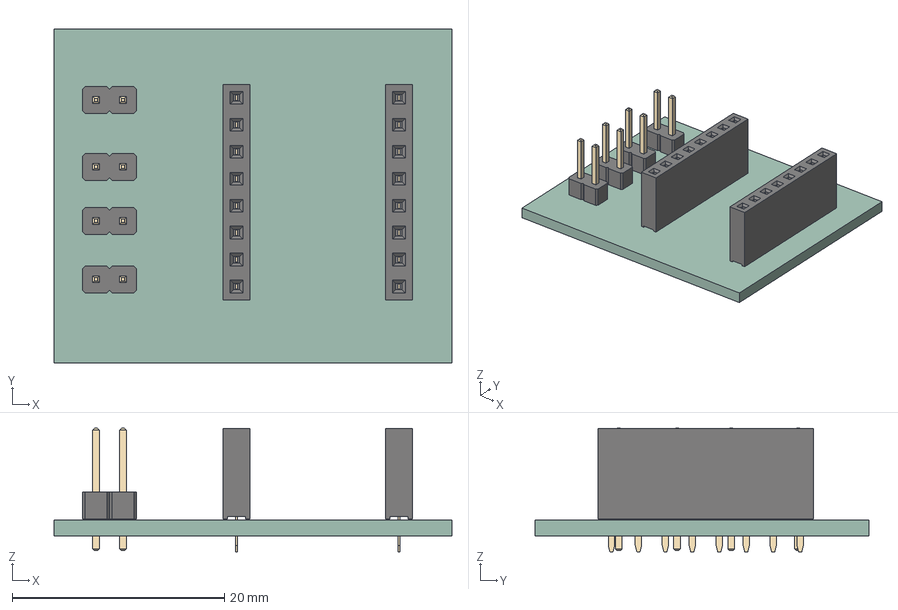
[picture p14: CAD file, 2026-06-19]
PCBs/HeadModule/Módulo Cabeza.step
37.5 x 31.5 x 11.6 mm
PinSocket_1x08_P2.54mm_Vertical x 2
PinHeader_1x02_P2.54mm_Vertical x 4
MÃ³dulo Cabeza_PCB

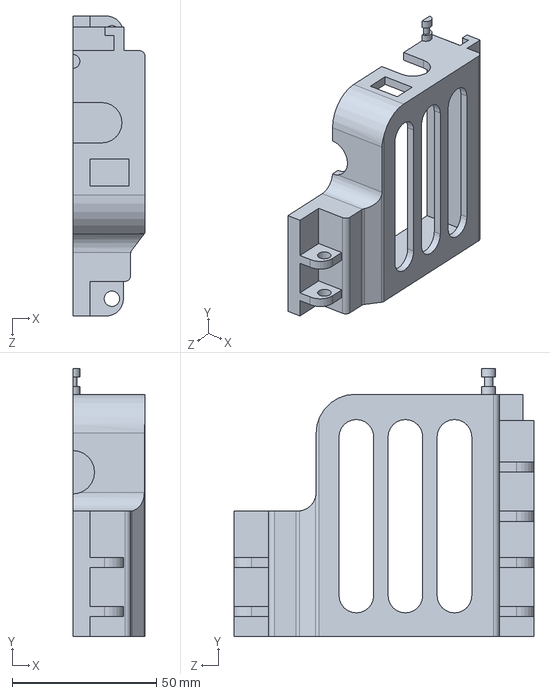
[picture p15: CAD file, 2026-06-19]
CAD_3D/Cabeza V3/Head_V3P2.SLDPRT
25.0 x 93.0 x 104.0 mm

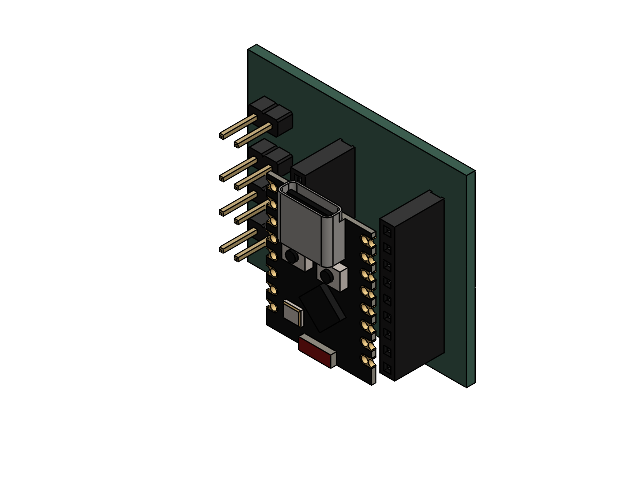
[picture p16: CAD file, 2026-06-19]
CAD_3D/Cabeza V3/PCB Módulo Cabeza.SLDASM
ESP32-C3 SuperMini
PinSocket_1x09_P2.54mm_Vertical.step x 2
PinHeader_1x02_P2.54mm_Vertical.step x 4
M____dulo Cabeza_PCB.step

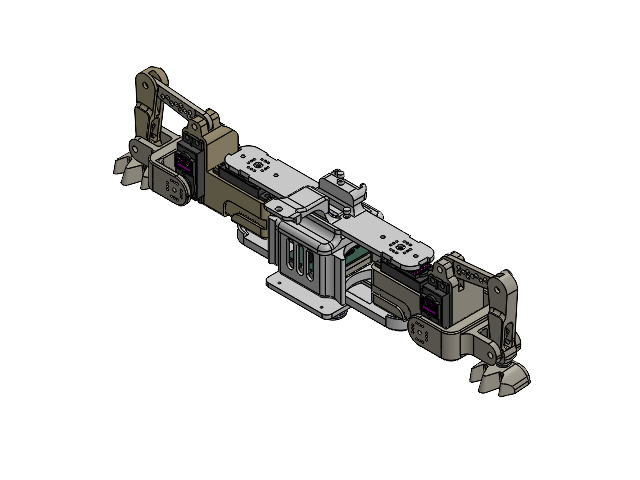
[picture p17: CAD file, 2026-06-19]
CAD_3D/Módulo de Patas V3/Ensamble Patas V3.SLDASM
Base MP V3
Eje Rodamiento Base x 2
Yaw_Servo
Rodamiento_2 x 4
mg996R_v21.step x 4
mg996R_v22.step x 4
mg996R_v23.step x 4
mg996R_v24.step x 4
mg996R_v25.step x 4
mg996R_v26.step x 4
mg996R_v27.step x 4
mg996R_v28.step x 4
mg996R_v29.step x 4
mg996R_v210.step x 4
mg996R_v211.step x 4
Servo Horns x 4
Hombro MP V3
Car_superiro MP V3
Alma MP V3
MirrorYaw_Servo
Bateria Patas x 2
link1 x 2
link1_1 x 2
link2 x 2
link3
Pie x 2
BaseBalin x 3
Balin x 3
TapaBaseBalin x 3
Mirrorlink3
PinHeader_1x02_P2.54mm_Vertical.step x 3
PinSocket_1x09_P2.54mm_Vertical.step x 2
PinHeader_1x03_P2.54mm_Vertical.step x 4
M____dulo Patas_PCB.step
ESP32-C3 SuperMini
Switch

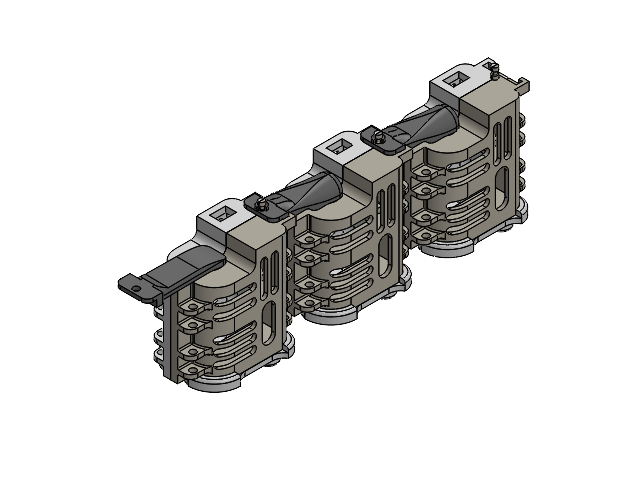
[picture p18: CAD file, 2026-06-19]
CAD_3D/Oscilatorio V4/osci_emsam_simpli.SLDASM
Osci_Ermetico x 3
osci_ermetico_2 x 3
Pieza conectora_V3 x 2
ClipOsc x 2
Pieza conectora Patas
PatínOsc_V2 x 3
Balin x 9

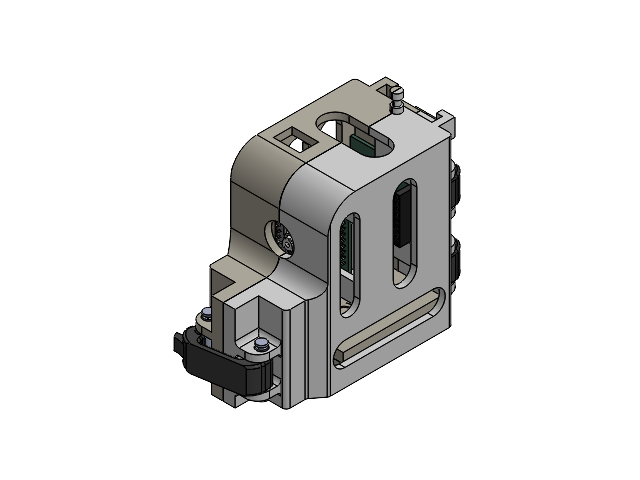
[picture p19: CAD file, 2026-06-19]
CAD_3D/Cabeza V3/Cabeza Assem.SLDASM
Head_V3
ESP32-C3 SuperMini
PinSocket_1x09_P2.54mm_Vertical.step x 2
PinHeader_1x02_P2.54mm_Vertical.step x 4
M____dulo Cabeza_PCB.step
esppart
PinSocket_1x08_P2.54mm_Vertical_1.step x 2
PinHeader_1x02_P2.54mm_Vertical_1.step
C____mara_PCB.step
Bateria Patas x 2
CLICK_CABEZA x 3
Tornillo Clip Cabeza x 2
Tornillo Clip Cabeza2 x 2
MirrorHead_V3P2

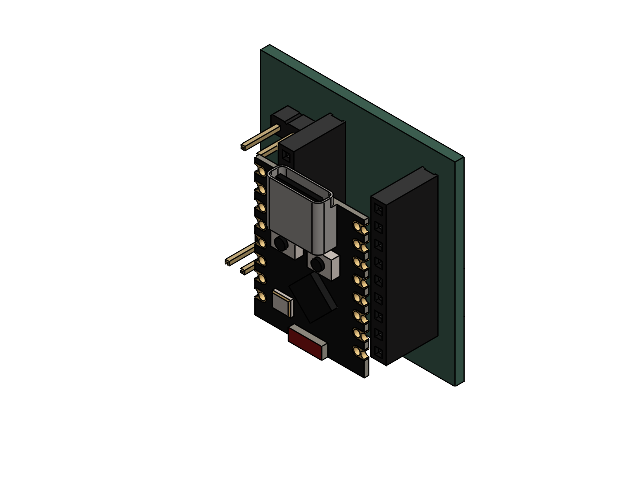
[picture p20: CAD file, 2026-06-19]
CAD_3D/Oscilatorio V4/Oscilatorio_PCB.SLDASM
PinHeader_1x03_P2.54mm_Vertical.step
PinSocket_1x09_P2.54mm_Vertical.step x 2
PinHeader_1x02_P2.54mm_Vertical.step
Oscilatorio_1_PCB.step
ESP32-C3 SuperMini

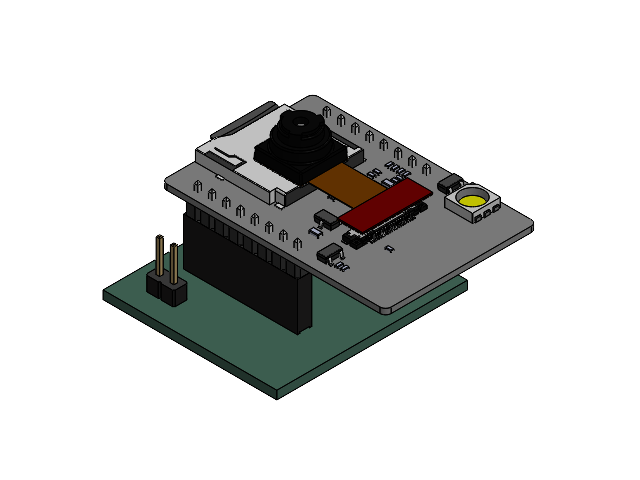
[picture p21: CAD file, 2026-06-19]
CAD_3D/Cabeza V3/PCB Cámara.SLDASM
esppart
PinSocket_1x08_P2.54mm_Vertical_1.step x 2
PinHeader_1x02_P2.54mm_Vertical_1.step
C____mara_PCB.step

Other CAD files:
CAD_3D/Módulo de Patas V3/Módulo Patas PCB.SLDASM
CAD_3D/Oscilatorio V4/mg996R_v2.SLDASM
CAD_3D/Módulo de Patas V3/mg996R_v2.SLDASM
CAD_3D/Módulo de Patas V3/Ensamble Patas Sim.SLDASM
CAD_3D/Cabeza V3/Bateria Patas.SLDPRT
CAD_3D/Cabeza V3/CLICK_CABEZA.SLDPRT
CAD_3D/Cabeza V3/Carcaza Cabeza Sally.SLDPRT
CAD_3D/Cabeza V3/ESP32-C3 SuperMini.SLDPRT
CAD_3D/Cabeza V3/MirrorHead_V3P2.SLDPRT
CAD_3D/Cabeza V3/Tornillo Clip Cabeza.SLDPRT
CAD_3D/Cabeza V3/Tornillo Clip Cabeza2.SLDPRT
CAD_3D/Cabeza V3/makeProjectedPlanarWire.x_t
CAD_3D/Cola/Pieza Conectora.SLDPRT
CAD_3D/Módulo de Patas V3/Alma MP V3.SLDPRT
CAD_3D/Módulo de Patas V3/Base MP V3.SLDPRT
CAD_3D/Módulo de Patas V3/Base MP V4.SLDPRT
CAD_3D/Módulo de Patas V3/Bateria Patas.SLDPRT
CAD_3D/Módulo de Patas V3/Car_superiro MP V3.SLDPRT
CAD_3D/Módulo de Patas V3/ESP32-C3 SuperMini.SLDPRT
CAD_3D/Módulo de Patas V3/Eje Rodamiento Base.SLDPRT
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

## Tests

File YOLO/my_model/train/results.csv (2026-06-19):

epoch | time | train/box_loss | train/cls_loss | train/dfl_loss | metrics/precision(B) | metrics/recall(B) | metrics/mAP50(B) | metrics/mAP50-95(B) | val/box_loss | val/cls_loss | val/dfl_loss | lr/pg0 | lr/pg1 | lr/pg2
1 | 70.1493 | 0.93748 | 2.59214 | 1.17509 | 0.84888 | 0.94697 | 0.94743 | 0.76986 | 0.70831 | 1.00101 | 0.96695 | 0.00024293 | 0.00024293 | 0.00024293
2 | 87.5254 | 0.72959 | 0.92307 | 1.01735 | 0.81049 | 0.84201 | 0.89818 | 0.65986 | 0.89021 | 1.30845 | 1.12707 | 0.000491898 | 0.000491898 | 0.000491898
3 | 118.58 | 0.79304 | 0.79283 | 1.04804 | 0.56539 | 0.62117 | 0.65271 | 0.4985 | 0.8992 | 1.41145 | 1.1506 | 0.000732377 | 0.000732377 | 0.000732377
4 | 147.277 | 0.80393 | 0.76467 | 1.0806 | 0.60448 | 0.32172 | 0.41881 | 0.24965 | 1.41425 | 4.21816 | 1.67992 | 0.000964368 | 0.000964368 | 0.000964368
5 | 177.744 | 0.83601 | 0.73885 | 1.09367 | 0.55722 | 0.55702 | 0.51251 | 0.31374 | 1.48847 | 1.79986 | 1.59794 | 0.00118787 | 0.00118787 | 0.00118787
6 | 206.71 | 0.81247 | 0.68067 | 1.04381 | 0.67688 | 0.59367 | 0.67495 | 0.45799 | 1.129 | 1.93806 | 1.54422 | 0.00131111 | 0.00131111 | 0.00131111
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

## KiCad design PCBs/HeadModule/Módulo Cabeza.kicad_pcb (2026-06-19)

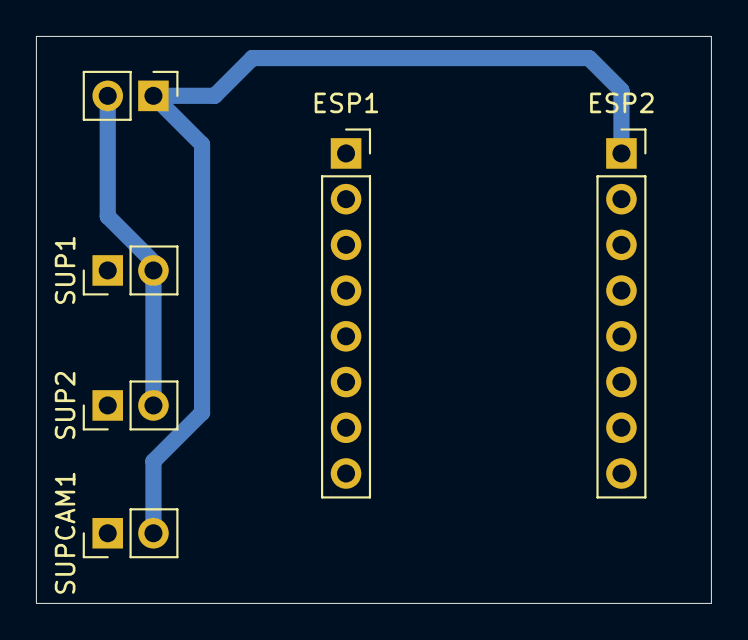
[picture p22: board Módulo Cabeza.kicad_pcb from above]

Board: 2 copper layers, 37.5 x 31.5 mm, 6 parts (0 on the bottom side), 3 nets.

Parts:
ESP1, ESP2: Conn_01x08; PinSocket_1x08_P2.54mm_Vertical
SUP1, SUP2: Supply; PinHeader_1x02_P2.54mm_Vertical
SUPCAM1: Supply; PinHeader_1x02_P2.54mm_Vertical
SWITCH1: Supply; PinHeader_1x02_P2.54mm_Vertical

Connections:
GND: ESP2.2, SUP1.1, SUP2.1, SUPCAM1.1
V+: ESP2.1, SUPCAM1.2, SWITCH1.1
VCC: SUP1.2, SUP2.2, SWITCH1.2

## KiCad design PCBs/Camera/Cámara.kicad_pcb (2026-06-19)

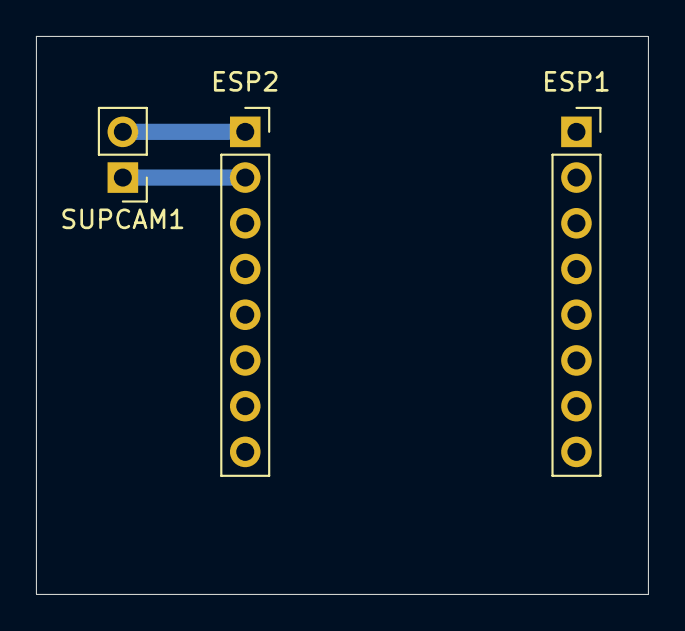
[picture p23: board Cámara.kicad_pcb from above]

Board: 2 copper layers, 34.0 x 31.0 mm, 3 parts (0 on the bottom side), 2 nets.

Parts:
ESP1, ESP2: Conn_01x08; PinSocket_1x08_P2.54mm_Vertical
SUPCAM1: Supply; PinHeader_1x02_P2.54mm_Vertical

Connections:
GND: ESP2.2, SUPCAM1.1
V+: ESP2.1, SUPCAM1.2

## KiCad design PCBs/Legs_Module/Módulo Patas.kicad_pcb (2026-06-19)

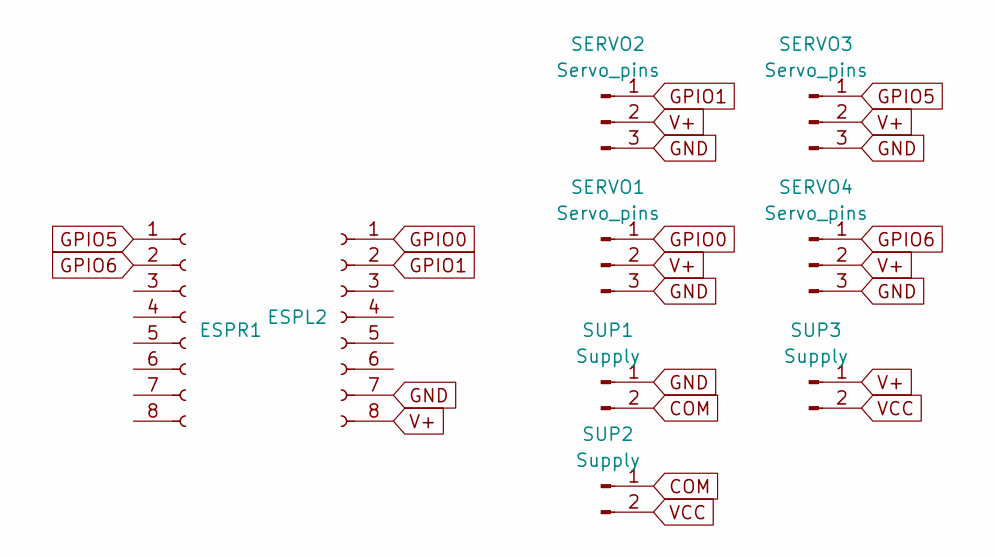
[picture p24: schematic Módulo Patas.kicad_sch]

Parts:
ESPL2: Conn_01x08_Socket; PinSocket_1x08_P2.54mm_Vertical
ESPR1: Conn_01x08_Socket; PinSocket_1x08_P2.54mm_Vertical
SERVO1, SERVO2, SERVO3, SERVO4: Servo_pins; PinHeader_1x03_P2.54mm_Vertical
SUP1, SUP2, SUP3: Supply; PinHeader_1x02_P2.54mm_Vertical

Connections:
COM: SUP1.2, SUP2.1
GND: ESPL2.7, SERVO1.3, SERVO2.3, SERVO3.3, SERVO4.3, SUP1.1
GPIO0: ESPL2.1, SERVO1.1
GPIO1: ESPL2.2, SERVO2.1
GPIO5: ESPR1.1, SERVO3.1
GPIO6: ESPR1.2, SERVO4.1
V+: ESPL2.8, SERVO1.2, SERVO2.2, SERVO3.2, SERVO4.2, SUP3.1
VCC: SUP2.2, SUP3.2

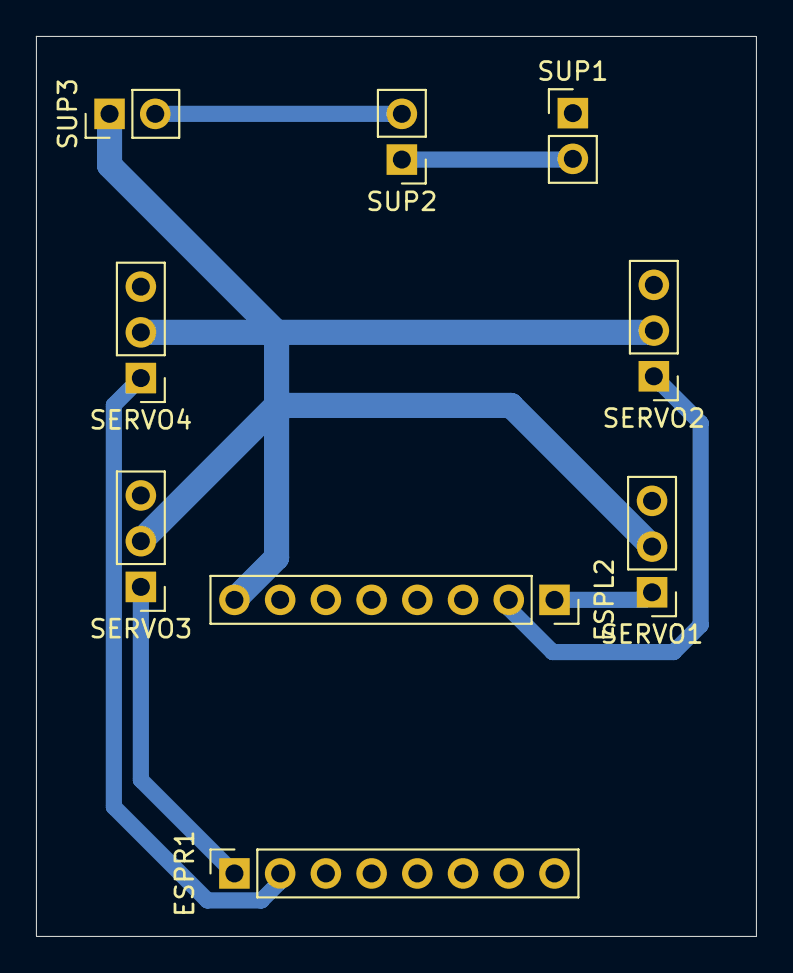
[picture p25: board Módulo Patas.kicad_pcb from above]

Board: 2 copper layers, 40.0 x 50.0 mm, 9 parts (0 on the bottom side), 8 nets.

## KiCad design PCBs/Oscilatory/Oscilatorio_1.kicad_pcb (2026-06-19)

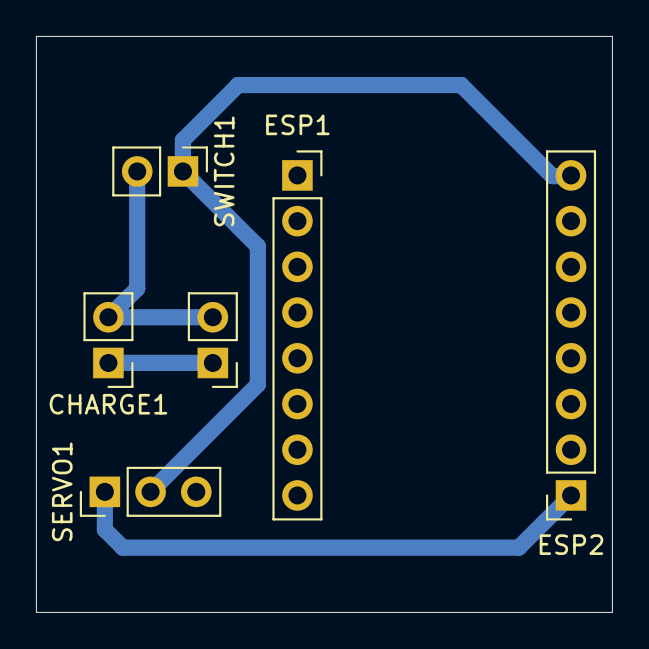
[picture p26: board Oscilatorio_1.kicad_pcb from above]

Board: 2 copper layers, 32.0 x 32.0 mm, 6 parts (0 on the bottom side), 4 nets.

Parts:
CHARGE1: Supply; PinHeader_1x02_P2.54mm_Vertical
ESP1, ESP2: Conn_01x08_Socket; PinSocket_1x08_P2.54mm_Vertical
SERVO1: Servo_pins; PinHeader_1x03_P2.54mm_Vertical
SUP1: Supply; PinHeader_1x02_P2.54mm_Vertical
SWITCH1: Supply; PinHeader_1x02_P2.54mm_Vertical

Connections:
GND: CHARGE1.1, ESP2.7, SERVO1.3, SUP1.1
GPIO0: ESP2.1, SERVO1.1
V+: ESP2.8, SERVO1.2, SWITCH1.1
VCC: CHARGE1.2, SUP1.2, SWITCH1.2

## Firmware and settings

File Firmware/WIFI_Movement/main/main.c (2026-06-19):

#include <string.h>
#include <stdio.h>
#include <stdlib.h>
#include <math.h>
#include "freertos/FreeRTOS.h"
#include "freertos/task.h"
#include "freertos/event_groups.h"
#include "esp_event.h"
#include "nvs_flash.h"
#include "esp_netif.h"
#include "esp_wifi.h"
#include "esp_log.h"
#include "esp_http_client.h"
#include "cJSON.h"

#include "driver/ledc.h"
#include "led_strip.h"

/* ========================= CONFIGURACIÓN ========================= */
#define AP_SSID             "SallyAP"
#define AP_PASS             "Sally1234"
#define DEVICE_ID           0                 // 0..7 (cambia en cada equipo)
#define DEFAULT_PERIOD_MS   2               // período por defecto si el server no lo envía
#define AP_IP               "192.168.4.1"     // IP SoftAP del servidor

#define USE_STATUS_LED      1                 // 1: usa el WS2812 del C3 en GPIO 8 como indicador
#define LED_STRIP_GPIO      8
#define LED_COUNT           1

/* Cómo mandar el ángulo al/los servo(s)
   0 = todos los servos
   1 = índice = DEVICE_ID % NUM_SERVOS   (POR DEFECTO)
   2 = índice fijo SERVO_FIXED_IDX
*/
#define SERVO_TARGET_MODE   1
#define SERVO_FIXED_IDX     0

/* ========================= TAGS (logs) ========================= */
static const char *TAG_WIFI  = "client_sta";
#define TAG_SERVO            "SERVOS"

/* ========================= NEURONS FILTERS (logs) ========================= */
#define NEU_N 4 
static const float tau = 3.0f;
static float z[NEU_N][2] = {{90.f,90.f}, {90.f,90.f}, {90.f,90.f}, {90.f,90.f}};

/* ========================= WIFI (STA) ========================= */
#define WIFI_CONNECTED_BIT BIT0
#define WIFI_GOT_IP_BIT    BIT1
static EventGroupHandle_t s_wifi_event_group;

static void wifi_event_handler(void* arg, esp_event_base_t event_base,
                               int32_t event_id, void* event_data) {
    if (event_base == WIFI_EVENT && event_id == WIFI_EVENT_STA_START) {
        esp_wifi_connect();
    } else if (event_base == WIFI_EVENT && event_id == WIFI_EVENT_STA_DISCONNECTED) {
        xEventGroupClearBits(s_wifi_event_group, WIFI_CONNECTED_BIT | WIFI_GOT_IP_BIT);
        vTaskDelay(pdMS_TO_TICKS(500));
        esp_wifi_connect();
    } else if (event_base == WIFI_EVENT && event_id == WIFI_EVENT_STA_CONNECTED) {
        xEventGroupSetBits(s_wifi_event_group, WIFI_CONNECTED_BIT);
    } else if (event_base == IP_EVENT && event_id == IP_EVENT_STA_GOT_IP) {
        xEventGroupSetBits(s_wifi_event_group, WIFI_GOT_IP_BIT);
    }
}

static void wifi_init_sta(void) {
    ESP_ERROR_CHECK(esp_netif_init());
    ESP_ERROR_CHECK(esp_event_loop_create_default());
    esp_netif_create_default_wifi_sta();

    wifi_init_config_t cfg = WIFI_INIT_CONFIG_DEFAULT();
    ESP_ERROR_CHECK(esp_wifi_init(&cfg));

    wifi_config_t wifi_config = { 0 };
    strncpy((char*)wifi_config.sta.ssid, AP_SSID, sizeof(wifi_config.sta.ssid));
    strncpy((char*)wifi_config.sta.password, AP_PASS, sizeof(wifi_config.sta.password));
    wifi_config.sta.threshold.authmode = WIFI_AUTH_WPA2_PSK;

    ESP_ERROR_CHECK(esp_wifi_set_mode(WIFI_MODE_STA));
    ESP_ERROR_CHECK(esp_wifi_set_config(WIFI_IF_STA, &wifi_config));
    ESP_ERROR_CHECK(esp_wifi_start());
    ESP_ERROR_CHECK(esp_wifi_connect());
    ESP_ERROR_CHECK(esp_event_handler_instance_register(WIFI_EVENT, ESP_EVENT_ANY_ID,
                                                        &wifi_event_handler, NULL, NULL));
    ESP_ERROR_CHECK(esp_event_handler_instance_register(IP_EVENT, IP_EVENT_STA_GOT_IP,
                                                        &wifi_event_handler, NULL, NULL));
    esp_wifi_set_ps(WIFI_PS_NONE);
    ESP_LOGI(TAG_WIFI, "Conectando a %s ...", AP_SSID);
}

/* ========================= LED RGB (opcional) ========================= */
#if USE_STATUS_LED
static led_strip_handle_t led_strip;

static void init_led_strip(void) {
    led_strip_config_t strip_cfg = {
        .strip_gpio_num = LED_STRIP_GPIO,
        .max_leds = LED_COUNT,
    };
    led_strip_rmt_config_t rmt_cfg = {
        .resolution_hz = 10 * 1000 * 1000,
        .flags.with_dma = false,
    };
    ESP_ERROR_CHECK(led_strip_new_rmt_device(&strip_cfg, &rmt_cfg, &led_strip));
    ESP_ERROR_CHECK(led_strip_clear(led_strip));
}

static void angle_to_rgb(int ang, uint8_t *R, uint8_t *G, uint8_t *B) {
    if (ang < 0) ang = 0;
    if (ang > 180) ang = 180;
    float t = ang / 180.0f; // 0..1
    float r = (t <= 0.5f) ? 0.0f : (t - 0.5f) * 2.0f;
    float g = (t <= 0.5f) ? (t * 2.0f) : (1.0f - r);
    float b = (t <= 0.5f) ? (1.0f - t*2.0f) : 0.0f;
    int brightness = 150;
    *R = (uint8_t)(r * brightness);
    *G = (uint8_t)(g * brightness);
    *B = (uint8_t)(b * brightness);
}

static void set_led_angle(int ang) {
    uint8_t R,G,B;
    angle_to_rgb(ang, &R,&G,&B);
    led_strip_set_pixel(led_strip, 0, R,G,B);
    led_strip_refresh(led_strip);
}
#endif

/* ========================= SERVOS (LEDC) ========================= */
/* GPIOs para tus servos (ajusta a gusto) */
static const int servo_pins[] = { 0, 1, 5, 6 };
#define NUM_SERVOS (sizeof(servo_pins)/sizeof(servo_pins[0]))

/* Un canal por servo */
static const ledc_channel_t servo_channels[NUM_SERVOS] = {
    LEDC_CHANNEL_0, LEDC_CHANNEL_1, LEDC_CHANNEL_2, LEDC_CHANNEL_3
};

/* PWM 50 Hz @ 14 bits (ESP32-C3) */
#define SERVO_MODE          LEDC_LOW_SPEED_MODE
#define SERVO_TIMER         LEDC_TIMER_0
#define SERVO_FREQ_HZ       (50)
#define SERVO_RES_BITS      (14)
#define SERVO_RESOLUTION    (ledc_timer_bit_t)LEDC_TIMER_14_BIT

/* Rango típico de pulso en microsegundos (ajústalo a tu servo) */
#define SERVO_MIN_US        (500)
#define SERVO_MAX_US        (2500)
#define SERVO_MIN_DEG       (0)
#define SERVO_MAX_DEG       (180)

static inline uint32_t duty_max(void) {
    return (1U << SERVO_RES_BITS) - 1U; // 16383 para 14 bits
}
static inline uint32_t period_us(void) {
    return 1000000UL / SERVO_FREQ_HZ;    // 20000 µs
}
static inline uint32_t clamp_u32(uint32_t v, uint32_t lo, uint32_t hi) {
    return (v < lo) ? lo : (v > hi ? hi : v);
}
static uint32_t us_to_duty(uint32_t pulse_us) {
    uint64_t num = (uint64_t)pulse_us * duty_max();
    return (uint32_t)(num / period_us());
}
static uint32_t deg_to_us(uint32_t deg) {
    deg = clamp_u32(deg, SERVO_MIN_DEG, SERVO_MAX_DEG);
    uint32_t span_us = SERVO_MAX_US - SERVO_MIN_US;
    uint64_t num = (uint64_t)(deg - SERVO_MIN_DEG) * span_us;
    return SERVO_MIN_US + (uint32_t)(num / (SERVO_MAX_DEG - SERVO_MIN_DEG));
}

static void servos_init(void) {
    ledc_timer_config_t tcfg = {
        .speed_mode       = SERVO_MODE,
        .duty_resolution  = SERVO_RESOLUTION,
        .timer_num        = SERVO_TIMER,
        .freq_hz          = SERVO_FREQ_HZ,
        .clk_cfg          = LEDC_AUTO_CLK,
    };
    ESP_ERROR_CHECK(ledc_timer_config(&tcfg));

    for (size_t i = 0; i < NUM_SERVOS; ++i) {
        ledc_channel_config_t ccfg = {
            .gpio_num   = servo_pins[i],
            .speed_mode = SERVO_MODE,
            .channel    = servo_channels[i],
            .intr_type  = LEDC_INTR_DISABLE,
            .timer_sel  = SERVO_TIMER,
            .duty       = 0,
            .hpoint     = 0
        };
        ESP_ERROR_CHECK(ledc_channel_config(&ccfg));

        uint32_t duty = us_to_duty(deg_to_us(90)); // centrar
        ESP_ERROR_CHECK(ledc_set_duty(SERVO_MODE, servo_channels[i], duty));
        ESP_ERROR_CHECK(ledc_update_duty(SERVO_MODE, servo_channels[i]));
        ESP_LOGI(TAG_SERVO, "Servo %d -> GPIO %d, canal %d OK", (int)i, servo_pins[i], servo_channels[i]);
    }
}

static void servo_write_us_idx(size_t idx, uint32_t pulse_us) {
    if (idx >= NUM_SERVOS) return;
    pulse_us = clamp_u32(pulse_us, SERVO_MIN_US, SERVO_MAX_US);
    uint32_t duty = us_to_duty(pulse_us);
    ledc_set_duty(SERVO_MODE, servo_channels[idx], duty);
    ledc_update_duty(SERVO_MODE, servo_channels[idx]);
}
static void servo_write_deg_idx(size_t idx, uint32_t deg) {
    servo_write_us_idx(idx, deg_to_us(deg));
    ESP_LOGI(TAG_SERVO, "Servo %d (GPIO %d) → %u°", (int)idx, servo_pins[idx], (unsigned)deg);
}

/* ========================= FETCH (HTTP → servo) ========================= */
static void fetch_task(void *arg) {
    char url[64];
    snprintf(url, sizeof(url), "http://%s/angle?id=%d", AP_IP, DEVICE_ID);
    ESP_LOGI(TAG_WIFI, "URL=%s", url);

    esp_http_client_config_t cfg = {
        .url = url,
        .timeout_ms = 2000,
        .buffer_size = 512,
        .keep_alive_enable = true,
    };
    esp_http_client_handle_t client = esp_http_client_init(&cfg);

    int curr_period = DEFAULT_PERIOD_MS;

    while (1) {
        esp_err_t err = esp_http_client_open(client, 0);
        if (err != ESP_OK) {
            ESP_LOGW(TAG_WIFI, "open fallo: %s", esp_err_to_name(err));
            vTaskDelay(pdMS_TO_TICKS(300));
            continue;
        }

        int64_t cl = esp_http_client_fetch_headers(client);
        ESP_LOGI(TAG_WIFI, "status=%d, content-length=%lld",
                 esp_http_client_get_status_code(client), cl);

        char buf[512];
        int total = 0;
        for (;;) {
            int r = esp_http_client_read(client, buf + total, sizeof(buf) - 1 - total);
            if (r > 0) {
                total += r;
                if (total >= (int)sizeof(buf) - 1) break;
            } else {
                break;
            }
        }
        buf[total] = 0;
        esp_http_client_close(client);

        if (total <= 0) {
            vTaskDelay(pdMS_TO_TICKS(300));
            continue;
        }

        ESP_LOGI(TAG_WIFI, "HTTP body len=%d", total);
        ESP_LOGI(TAG_WIFI, "HTTP body: %.*s", total, buf);

                cJSON *root = cJSON_Parse(buf);
        if (!root) {
            ESP_LOGW(TAG_WIFI, "JSON inválido");
            vTaskDelay(pdMS_TO_TICKS(200));
            continue;
        }

        // Lee periodo recomendado (si viene)
        cJSON *pms = cJSON_GetObjectItem(root, "period_ms");
        if (cJSON_IsNumber(pms) && pms->valueint >= 20 && pms->valueint <= 5000) {
            // curr_period = pms->valueint;
        }

        // --- PATH 1: paquete de patas (count=4) -> 4 servos ---
        bool drove_servos = false;
        cJSON *count = cJSON_GetObjectItem(root, "count");
        if (cJSON_IsNumber(count) && count->valueint == 4) {
            cJSON *angles = cJSON_GetObjectItem(root, "angles");
            if (cJSON_IsArray(angles) && cJSON_GetArraySize(angles) >= 4) {
                int a0 = cJSON_GetArrayItem(angles, 0)->valuedouble;
                int a1 = cJSON_GetArrayItem(angles, 1)->valuedouble;
                int a2 = cJSON_GetArrayItem(angles, 2)->valuedouble;
                int a3 = cJSON_GetArrayItem(angles, 3)->valuedouble;

                // Clamp 0..180 por seguridad
                if (a0 < 0) { a0 = 0; }
                if (a0 > 180) { a0 = 180; }

                if (a1 < 0) { a1 = 0; }
                if (a1 > 180) { a1 = 180; }

                if (a2 < 0) { a2 = 0; }
                if (a2 > 180) { a2 = 180; }

                if (a3 < 0) { a3 = 0; }
                if (a3 > 180) { a3 = 180; }


                // Mapea 1:1 a tus 4 servos (GPIO 0,1,5,6)
                z[0][1]=z[0][0]+(curr_period/tau)*(-z[0][0]+(a0));
                z[1][1]=z[1][0]+(curr_period/tau)*(-z[1][0]+(a1));
                z[2][1]=z[2][0]+(curr_period/tau)*(-z[2][0]+(a2));
                z[3][1]=z[3][0]+(curr_period/tau)*(-z[3][0]+(a3));

                // servo_write_deg_idx(0, (uint32_t)(z[0][1]));
                // servo_write_deg_idx(1, (uint32_t)(z[1][1]));
                // servo_write_deg_idx(2, (uint32_t)(z[2][1]));
                // servo_write_deg_idx(3, (uint32_t)(z[3][1]));

                servo_write_deg_idx(0, (uint32_t)(a0));
                servo_write_deg_idx(1, (uint32_t)(a1));
                servo_write_deg_idx(2, (uint32_t)(a2));
                servo_write_deg_idx(3, (uint32_t)(a3));

                ESP_LOGI(TAG_SERVO, "Patas[0] = [%d, %d, %d, %d] → servos 0..3", a0,a1,a2,a3);

                // (opcional) LED de estado: promedio para color
                #if USE_STATUS_LED
                set_led_angle((a0 + a1 + a2 + a3) / 4);
                #endif

                drove_servos = true;
            }
        }

        // --- PATH 2: módulo de 1 servo (count=1 / angle) ---
        if (!drove_servos) {
            int angle_val = -1;
            cJSON *angle = cJSON_GetObjectItem(root, "angle");
            if (cJSON_IsNumber(angle)) {
                angle_val = angle->valueint;
            } else if (cJSON_IsString(angle) && angle->valuestring) {
                angle_val = atoi(angle->valuestring);
            }
            if (angle_val >= 0) {
                // Por defecto, usa el índice basado en DEVICE_ID
                size_t idx = 0;
                servo_write_deg_idx(idx, (uint32_t)angle_val);
                ESP_LOGI(TAG_SERVO, "OSC[%d] = %d° → servo %d", DEVICE_ID, angle_val, (int)idx);

                #if USE_STATUS_LED
                set_led_angle(angle_val);
                #endif
            } else {
                ESP_LOGW(TAG_WIFI, "No pude extraer 'angle' ni 'angles[4]'");
            }
        }

        cJSON_Delete(root);

        vTaskDelay(pdMS_TO_TICKS(curr_period));
    }
}

/* ========================= app_main ========================= */
void app_main(void) {
    /* Inicializa NVS (Wi-Fi lo requiere) */
    esp_err_t ret = nvs_flash_init();
    if (ret == ESP_ERR_NVS_NO_FREE_PAGES || ret == ESP_ERR_NVS_NEW_VERSION_FOUND) {
        ESP_ERROR_CHECK(nvs_flash_erase());
        ret = nvs_flash_init();
    }

    s_wifi_event_group = xEventGroupCreate();
    wifi_init_sta();

    /* LED indicador (opcional) */
    #if USE_STATUS_LED
    init_led_strip();
    #endif

    /* Servos */
    servos_init();

    /* Espera vínculo + IP y arranca fetch */
    xEventGroupWaitBits(s_wifi_event_group,
                        WIFI_CONNECTED_BIT | WIFI_GOT_IP_BIT,
                        pdFALSE, pdTRUE, portMAX_DELAY);
    ESP_LOGI(TAG_WIFI, "Todo Ready");
    xTaskCreate(fetch_task, "fetch_task", 4096*3, NULL, 5, NULL);
}

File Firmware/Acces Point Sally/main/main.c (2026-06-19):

// Sally - Maestro SoftAP con marchas + calibración por offsets (NVS)
// Basado en tu código base de marchas; integra /mode (run|calib|idle) y /calib (GET/POST).
// - En MODE_CALIB publica 90° en todos los canales (vista neutra).
// - En MODE_RUN aplica offsets guardados a las LUT antes de publicar.
// - Offsets persistidos en NVS ("sally"/"offsets") como 14 enteros signed (-45..+45).

#include <string.h>
#include <stdio.h>
#include <stdlib.h>
#include <math.h>
#include "freertos/FreeRTOS.h"
#include "freertos/task.h"
#include "esp_event.h"
#include "nvs_flash.h"
#include "nvs.h"
#include "esp_netif.h"
#include "esp_wifi.h"
#include "esp_log.h"
#include "esp_system.h"
#include "esp_mac.h"
#include "esp_http_server.h"
#include "esp_timer.h"

#ifndef M_PI
#define M_PI 3.14159265358979323846
#endif

// ======= AP config =======
static const char *TAG = "Master_AP";
#define AP_SSID     "SallyAP"
#define AP_PASS     "Sally1234"
#define AP_CHANNEL  6
#define AP_MAX_CONN 8

// ======= Banco de 8 IDs (mixto 1 o 4 ángulos) =======
typedef struct {
    uint8_t count;  // 1 o 4
    int     a[4];   // usa a[0..count-1]
} dev_payload_t;

static dev_payload_t bank[8] = {
    {4, { 90, 90, 90, 90}}, // ID 0  (patas frente: 4)
    {1, { 90,  0,  0,  0}}, // ID 1  (spine 0)
    {1, { 90,  0,  0,  0}}, // ID 2  (spine 1)
    {1, { 90,  0,  0,  0}}, // ID 3  (spine 2)
    {4, { 90, 90, 90, 90}}, // ID 4  (patas traseras: 4)
    {1, { 90,  0,  0,  0}}, // ID 5  (spine 3)
    {1, { 90,  0,  0,  0}}, // ID 6  (spine 4)
    {1, { 90,  0,  0,  0}}, // ID 7  (spine 5)
};

// ======= Parámetros de marcha =======
static volatile int   period_ms       = 50;         // periodo de actualización ("FPS")
static volatile int   gait_period_ms  = 1300;       // ciclo de marcha
static volatile float max_dps         = 125.0f;     // límite vel. (°/s)

// Modos de paso
typedef enum { GAIT_TROT = 0, GAIT_WALK = 1 } gait_t;
static volatile gait_t gait_mode = GAIT_WALK;

// Bias/amplitudes (°)
static volatile float hip_amp_deg    = 50.0f;
static volatile float hip_bias_deg   = 90.0f;
static volatile float knee_amp_deg   = 18.0f;
static volatile float knee_bias_deg  = 110.0f;

static volatile float spine_amp_deg  = 50.0f;
static volatile float spine_bias_deg = 90.0f;
static volatile float spine_dphi_rad = (float)M_PI/6.0f;

// LUTs
#define LUT_N 200
static int16_t lut_legs_front[4][LUT_N]; // [FR_hip, FR_knee, FL_hip, FL_knee]
static int16_t lut_legs_rear [4][LUT_N]; // [RR_hip, RR_knee, RL_hip, RL_knee]
static int16_t lut_spine     [6][LUT_N]; // spine 0..5
static volatile int lut_idx = 0;

// Estado suavizado
static int16_t cur_id0[4], cur_id4[4], cur_spine[6];
static esp_timer_handle_t g_timer = NULL;

// Acoplamiento columna↔patas
static volatile float spine_gain_fore_deg = 15.0f;
static volatile float spine_gain_hind_deg = 15.0f;
// ===== Pesos de columna (acople patas↔columna) por marcha =====
// Marcha frontal (recto)
static const float W_fore_F[6] = { 1.25f, 0.00f,  0.4f, 0.5f, 0.2f, 0.0f };
static const float W_hind_F[6] = { 0.40f, 1.00f, -5.25f, 0.8f, 1.25f, 2.0f };
// Marcha hacia la IZQUIERDA
static const float W_fore_L[6] = { 5.25f, 0.00f, 0.40f, 0.5f, 0.2f, 0.0f };
static const float W_hind_L[6] = { 0.40f, 3.00f, -5.25f, 0.8f, 1.25f, 2.0f };
// Marcha hacia la DERECHA
static const float W_fore_R[6] = { 1.25f, 0.75f, 0.40f, 0.50f, 0.20f, 0.00f };
static const float W_hind_R[6] = { 0.40f, 0.75f, 1.25f, 0.80f, 1.25f, 2.00f };

// Dirección (ya existente en tu lógica)
volatile int8_t  turn_cmd          = 0;     // -1 der, 0 recto, +1 izq
volatile float   turning_percentage = 0.50f; // 0..1
volatile float   k_response         = 0.50f; // 0..1

// ===== Drift lateral constante (bias de giro) =====
// turn_bias ∈ [-1..+1]; positivo favorece GIRO A LA IZQUIERDA.
// Para compensar centro de masa cargado a la derecha, usa +0.30 (30%).
static volatile float turn_bias = 0.35;

// Conducción / congelado
typedef enum { DRIVE_STOP=0, DRIVE_FORWARD=1, DRIVE_LEFT=2, DRIVE_RIGHT=3 } drive_mode_t;
static volatile drive_mode_t drive_mode = DRIVE_STOP;
static volatile bool freeze_motion = false;

// ======= NUEVO: Modo general de control (incluye calibración) =======
typedef enum { MODE_IDLE=0, MODE_DRIVE=1, MODE_CALIB=2, MODE_PREVIEW=3 } ctrl_mode_t;
static volatile ctrl_mode_t g_mode = MODE_IDLE;

static volatile float spine_skew = 1.0f;       // -1 ó +1
static volatile float SPINE_SKEW_GAIN = 0.75f;  // 60% de asimetría máxima

// ======= NUEVO: Offsets de calibración (mapa 14 canales) =======
// Orden de offsets ↔ banco:
// 0..3  -> bank[0].a[0..3]
// 4..6  -> bank[{1,2,3}].a[0]
// 7..10 -> bank[4].a[0..3]
// 11..13-> bank[{5,6,7}].a[0]
#define SERVO_COUNT 14
static int8_t g_offset_deg[SERVO_COUNT]; // -45..+45

// ======= Helpers =======
static inline float smoothstepf(float t) {
    if (t <= 0.0f) return 0.0f;
    if (t >= 1.0f) return 1.0f;
    return t*t*(3.0f - 2.0f*t);
}
static inline int clamp_deg(int v) { if (v < 0) return 0; if (v > 180) return 180; return v; }
static inline int16_t approach_deg(int16_t cur, int16_t target, float dt_s, float max_deg_per_s) {
    float max_step = max_deg_per_s * dt_s;
    float d = (float)target - (float)cur;
    if (d >  max_step) d =  max_step;
    if (d < -max_step) d = -max_step;
    int val = (int)lrintf((float)cur + d);
    return (int16_t)clamp_deg(val);
}

// Perfil de pata (apoyo/vuelo)
static inline void leg_profile(float u, float duty, float dir,
                               float hip_bias, float hip_amp_stance, float hip_amp_swing,
                               float knee_bias, float knee_amp_stance, float knee_amp_swing,
                               float* hip_out, float* knee_out)
{
    u = u - floorf(u);
    if (u < duty) {
        float s  = u / duty;
        float sh = smoothstepf(s);
        float hip_rel  = (1.0f - 2.0f*sh);
        float hip_val  = hip_bias + dir * -1.0f * hip_amp_stance * hip_rel;
        float k_rel    = 1.0f - 0.2f * cosf((float)M_PI * (2.0f*sh - 1.0f));
        float knee_val = knee_bias + dir * -1.0f * (knee_amp_stance * (k_rel - 1.0f));
        *hip_out  = hip_val;
        *knee_out = knee_val;
    } else {
        float s  = (u - duty) / (1.0f - duty);
        float sh = smoothstepf(s);
        float hip_rel  = (-1.0f + 2.0f*sh);
        float hip_val  = hip_bias + dir * -1.0f * hip_amp_swing * hip_rel;
        float bell     = sinf((float)M_PI * sh);
        float knee_val = knee_bias + dir * -1.0f * (knee_amp_swing * bell);
        *hip_out  = hip_val;
        *knee_out = knee_val;
    }
}
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

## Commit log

2026-06-28 update git ignore
    [.uncrustify.cfg, cmn_crt_authorities.csv, esp_efuse_table.csv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]
2026-06-28 update ncs deletions
    [Cámara-B_Cu.gbr, Cámara-Edge_Cuts.gbr, Cámara-NPTH.drl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]
2026-06-28 update backups deletions
    [Oscilatorio_1-job.gbrjob]
